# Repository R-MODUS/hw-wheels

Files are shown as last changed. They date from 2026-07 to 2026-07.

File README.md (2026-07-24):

# hw-wheels

Wheels in this repository belong to the [R-MODUS](https://github.com/R-MODUS) project, but they can be reused in other robots as well.

All variants are currently designed for a **Ø 6 mm** motor shaft.

This repo is **mechanical only** — no firmware or ROS.

## Variants

| Preview | Variant | Summary |
| --- | --- | --- |
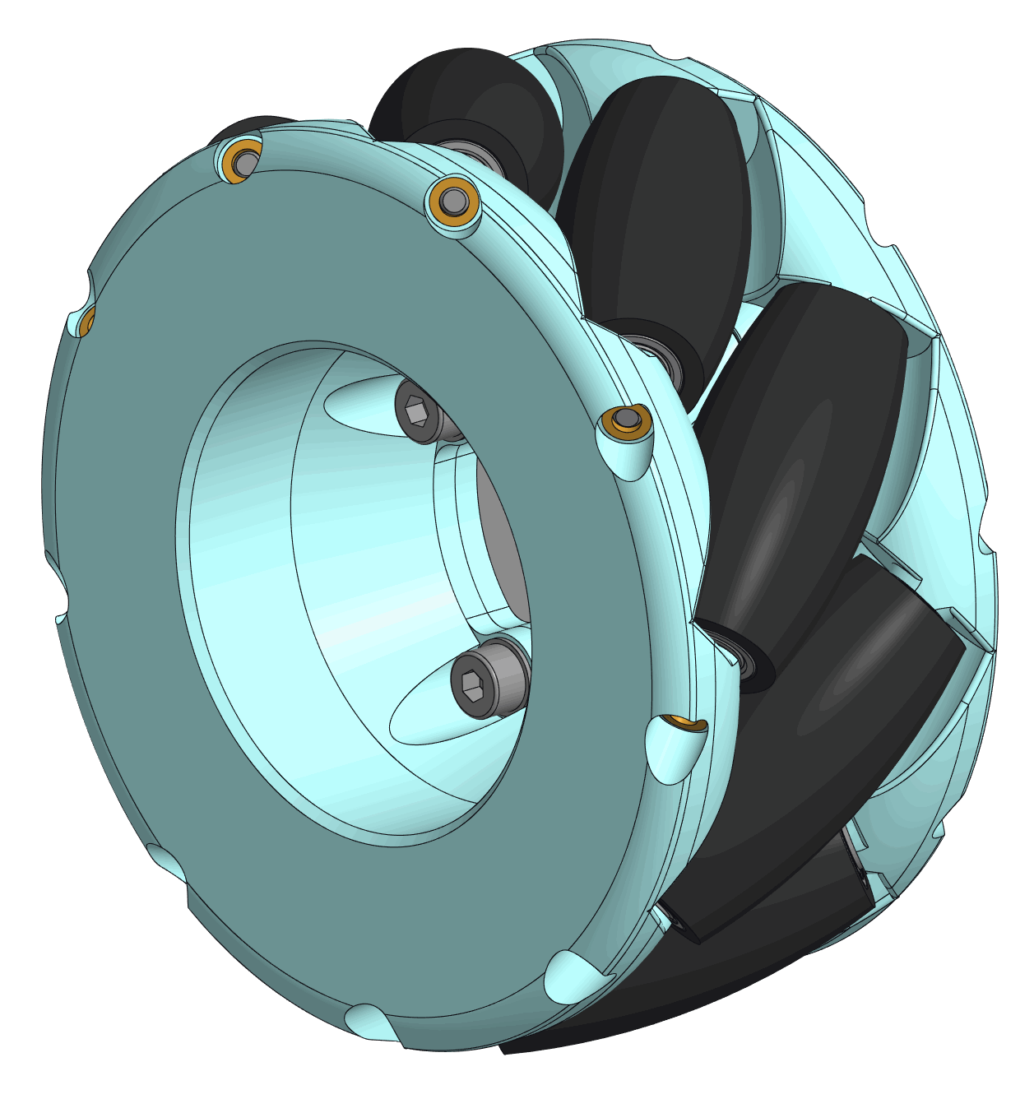
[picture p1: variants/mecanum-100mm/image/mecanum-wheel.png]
mecanum-100mm
|  | [`mecanum-100mm`](variants/mecanum-100mm/) | Omnidirectional mecanum wheel, Ø 100 mm, 9 rollers |
| — | [`simple-100mm`](variants/simple-100mm/) | Simple 3D-printed wheel, Ø 100 mm |

## Licence

[MIT](LICENSE)

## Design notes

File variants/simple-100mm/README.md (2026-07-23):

# simple-100mm

<!-- Placeholder — docs and files for this variant will go here. -->

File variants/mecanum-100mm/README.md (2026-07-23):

# Mecanum Wheel 100mm

Part of the [R-MODUS](https://github.com/R-MODUS) project — a modular indoor robot navigation stack — but this wheel can be used in other projects on its own.

<p align="center">
  Mecanum wheel 100 mm
  &nbsp;
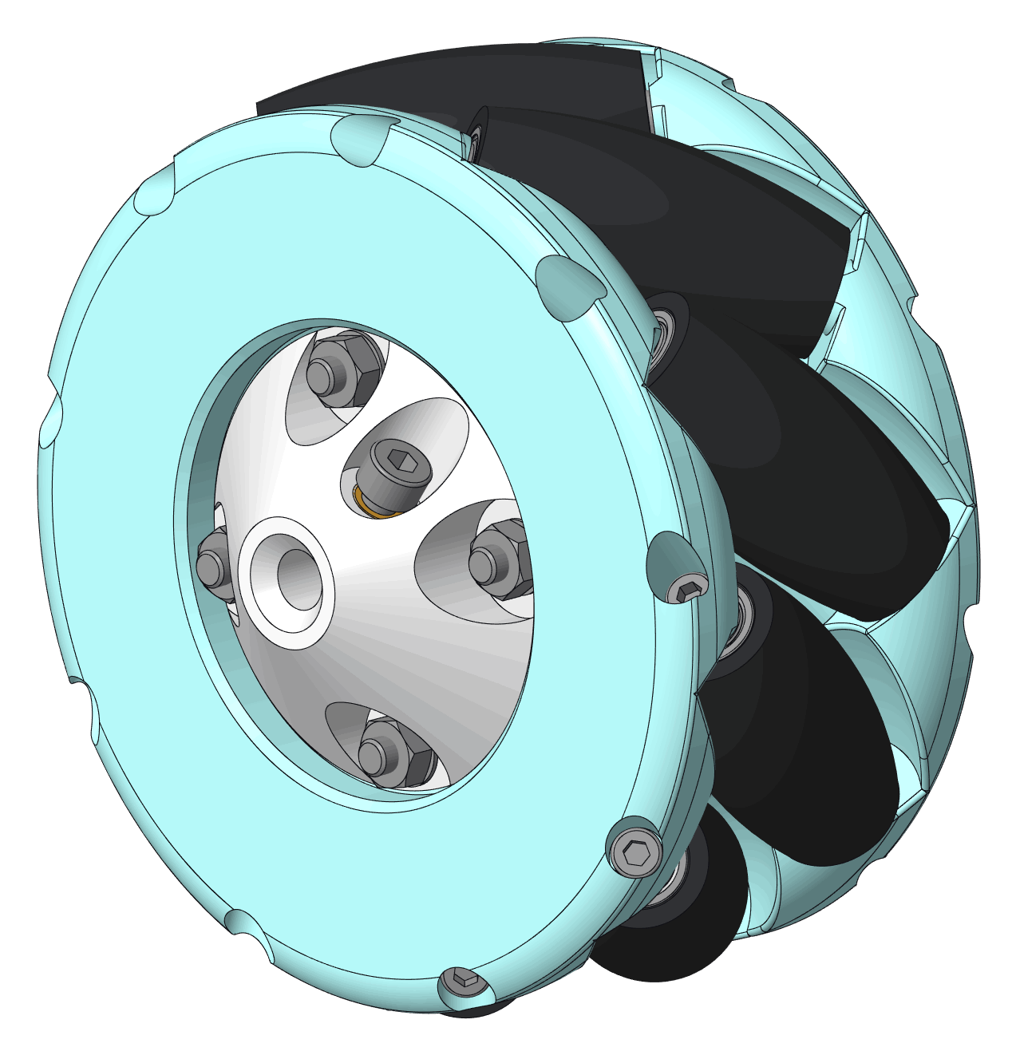
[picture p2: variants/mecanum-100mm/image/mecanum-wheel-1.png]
Mecanum wheel — detail
  
</p>

## Parameters

| Parameter | Value |
| --- | --- |
| Wheel diameter | 100 mm |
| Wheel width | 46 mm |
| Width with motor bushing | 56 mm |
| Number of rollers | 9 |
| Shaft bore | Ø 6 mm |
| Mass | ~0.33 kg |
| Part material | PLA (3D print) |
| Roller surface | polyolefin |

## Bill of materials (one wheel)

A typical chassis uses 4× (2× standard + 2× mirrored).

| Item | Qty | Note |
| --- | --- | --- |
| Outer ring | 1 | `mecanum-outer-ring.stp` |
| Inner ring | 1 | `mecanum-inner-ring.stp` |
| Shaft interface | 1 | `mecanum-shaft-interface.stp` |
| Roller | 9 | `mecanum-cylinder.stp` |
| Bearing 623 | 18 | 2× per roller |
| Heat-shrink tubing Ø20 mm | 40 cm | electrical grade |
| Screw M4×14 DIN 912 | 4 | — |
| Screw M4×10 DIN 912 | 1 | — |
| Screw M3×50 DIN 912 | 9 | — |
| Nut M4 DIN 934 | 4 | hex |
| Washer 4 DIN 125 A | 4 | — |
| Washer 3 DIN 125 A | 18 | — |
| Heat insert M4 | 1 | brass, Ø6.3 × L 6 mm |
| Heat insert M3 | 9 | brass, Ø4.6 × L 5 mm |

## Assembly

1. Thoroughly clean all printed parts.
2. Cut the heat-shrink tubing into 4 cm pieces, slide them onto the rollers, and shrink with a heat gun (warm gently only so the roller does not deform).
3. In a vise, press two bearings into each roller — one from each side.

<p align="center">
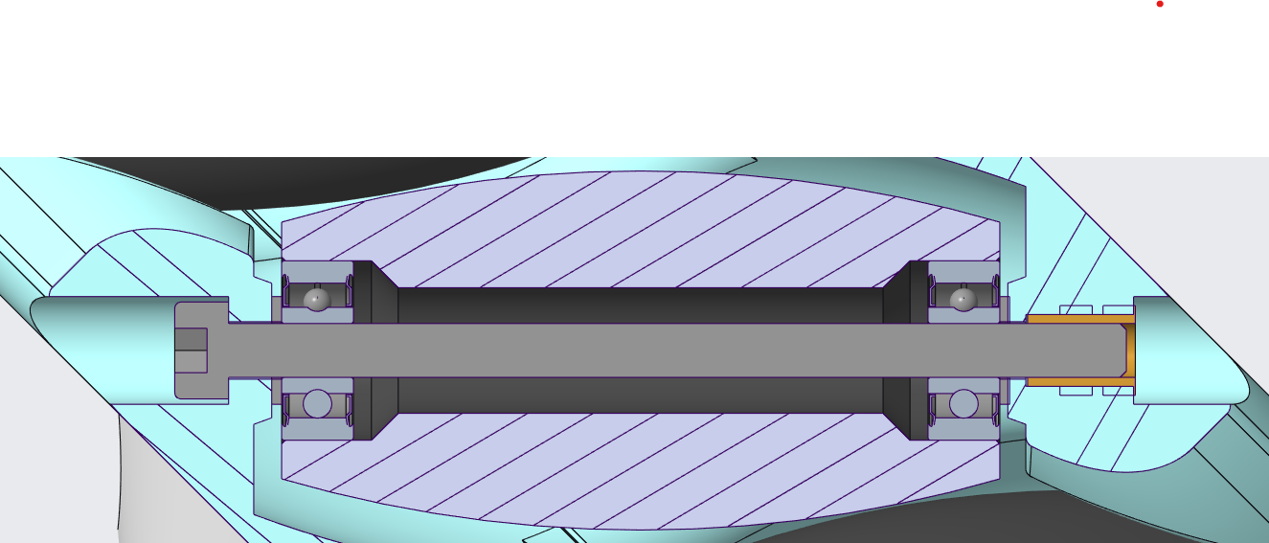
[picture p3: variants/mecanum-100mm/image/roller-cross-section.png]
Roller cross-section — tubing, bearings, screw
  
</p>

4. Melt-install the M3 heat inserts into the outer ring.
5. Melt-install the M4 heat insert into the shaft interface.
6. Stack the shaft interface and both rings; lightly clamp them with four M4×14 screws and nuts. Place washers under the nuts. Orient screw heads toward the outer ring.
7. Insert the rollers one by one and secure them with M3×50 screws; put a washer on each side next to the bearing and tighten carefully.
8. Fully tighten the four M4 screws to lock the rings.
9. Fine-tune: tighten each M3 screw so the roller spins freely but has no axial play.

### Mounting on the motor

1. Slide the wheel onto the Ø 6 mm motor shaft.
2. Secure the wheel with an M4×10 screw.

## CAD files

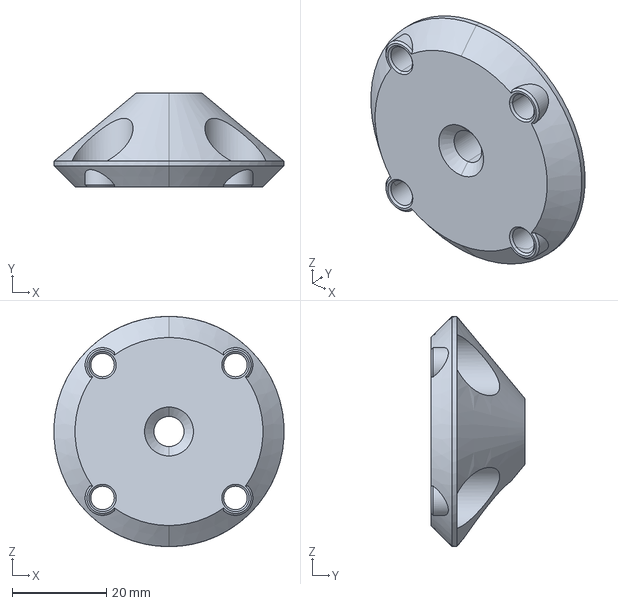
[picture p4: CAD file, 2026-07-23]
variants/mecanum-100mm/cad/exports/prt_3_4_shaft_clamp.stp
48.9 x 20.0 x 49.0 mm

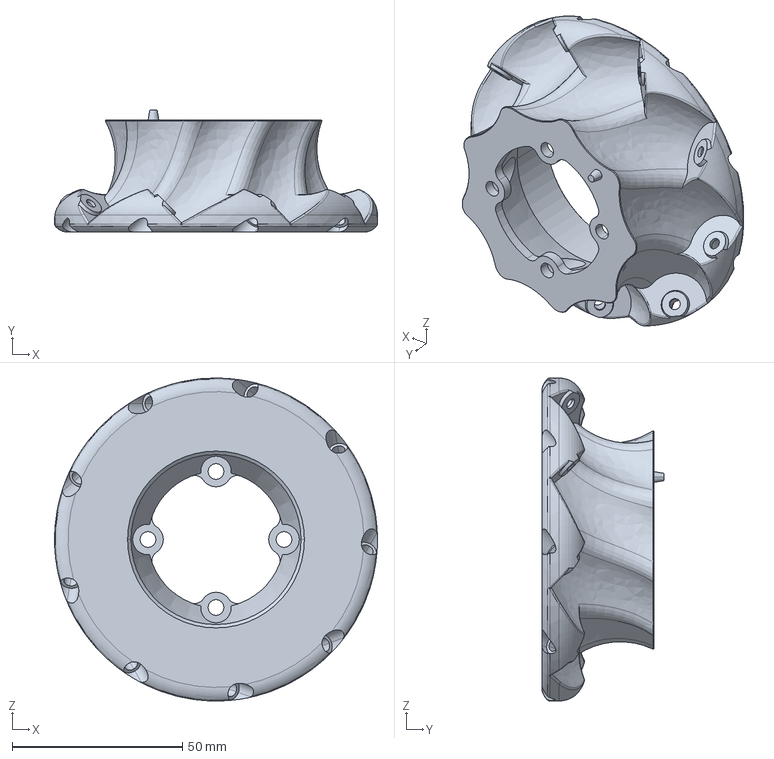
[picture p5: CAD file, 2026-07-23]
variants/mecanum-100mm/step/mecanum-outer-ring.stp
95.0 x 36.0 x 95.0 mm

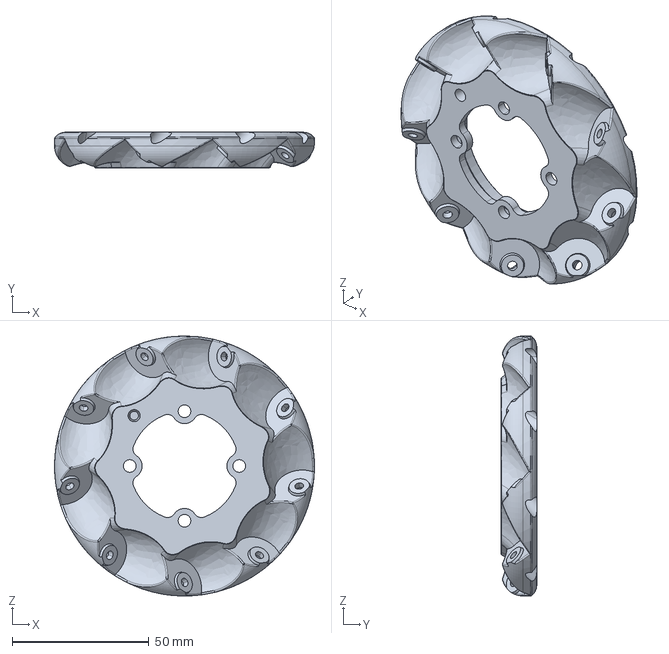
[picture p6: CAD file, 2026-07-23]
variants/mecanum-100mm/step/mecanum-inner-ring.stp
95.0 x 13.0 x 95.0 mm

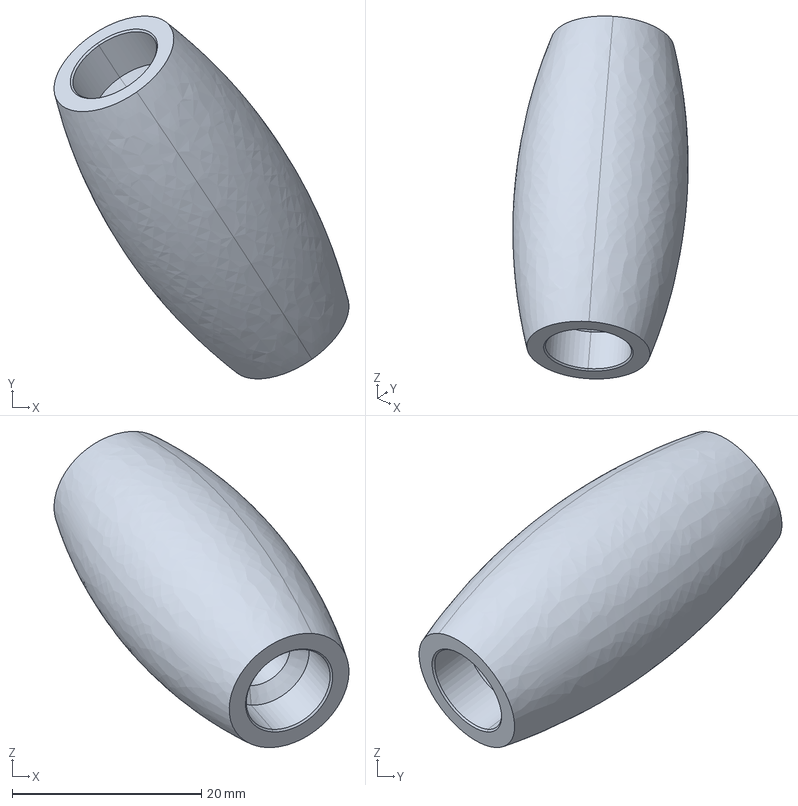
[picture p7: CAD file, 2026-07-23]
variants/mecanum-100mm/step/mecanum-cylinder.stp
31.2 x 38.4 x 33.4 mm

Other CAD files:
variants/mecanum-100mm/step/mecanum-shaft-interface.stp
